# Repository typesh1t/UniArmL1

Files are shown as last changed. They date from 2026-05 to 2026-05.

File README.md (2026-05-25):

<div align="center">

# UniArmL1

  <a href="https://www.unitree.com/" target="_blank">
    Unitree LOGO
  </a>

**UniArmL1** 开源 6-DOF 机械臂及遥操作框架

<!-- [![English](https://img.shields.io/badge/English-README-blue)](./README.md) [![中文](https://img.shields.io/badge/中文-README-green)](./README_zh.md) -->

</div>

<div align="center">
<table>
  <tr>
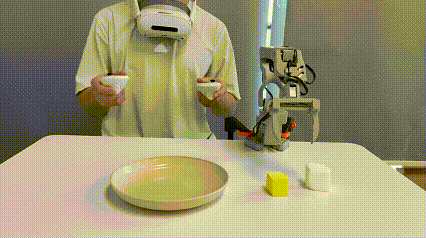
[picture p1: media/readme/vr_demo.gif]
VR demo
    <td></td>
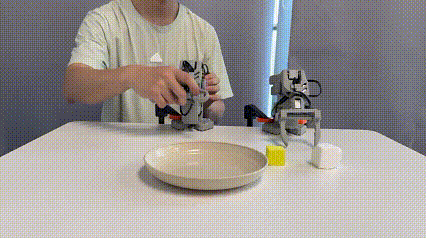
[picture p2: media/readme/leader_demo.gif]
Leader demo
    <td></td>
  </tr>
</table>
</div>

## ✳️ 概述

当前项目 UniArmL1 是一个轻量化的开源 6-DOF 机械臂及遥操作框架，支持三种控制模式与标准化数据采集，采集数据可无缝对接 [unitree_lerobot](https://github.com/unitreerobotics/unitree_lerobot) 进行模仿学习训练与部署。

**核心功能：**

- 🎮 **遥操作控制** — VR 手柄 / 键盘 / 主从臂三种模式实时控制 UniArmL1
- 📦 **数据采集** — 固定频率录制关节角度与相机图像，输出标准格式数据集
- 🔄 **训练对接** — 采集数据可直接用于 [unitree_lerobot](https://github.com/unitreerobotics/unitree_lerobot) 模仿学习训练

**完整流程：**

`硬件准备` → `校准` → `配置环境` → `遥操作 & 数据采集` → `训练` → `部署`

## 🔧 硬件准备

UniArmL1 机械臂的BOM 清单、组装指南与 3D 打印文件请参考：

👉 [unitree_UniArmL1_hardware](hardware/README_zh-CN.md)

<div align="center">
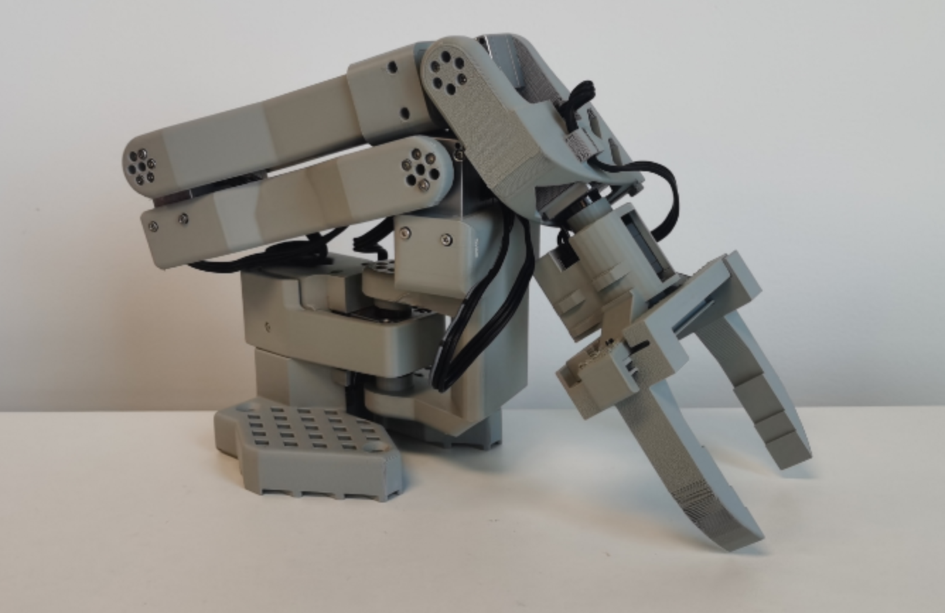
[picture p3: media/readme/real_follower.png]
Follower
   
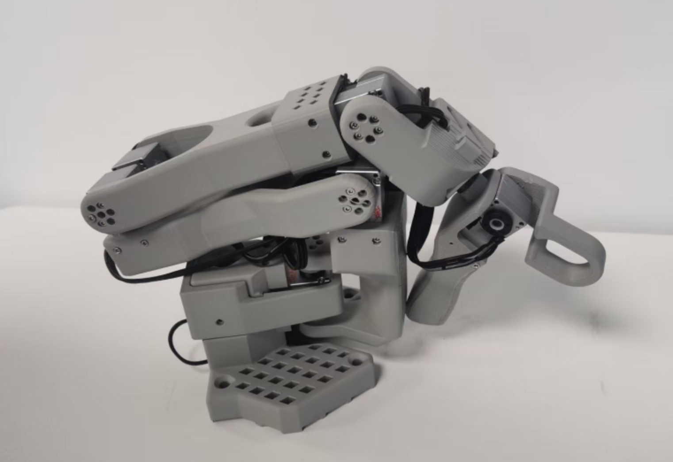
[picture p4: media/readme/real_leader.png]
Leader
    
</div>

## 📥 配置环境

### **1. 克隆仓库**

```bash
git clone https://github.com/unitreerobotics/UniArmL1
cd UniArmL1
```

### **2. 安装依赖**

该脚本会安装全部依赖（含VR模式）：
```bash
bash setup.sh
```

### **3. VR环境配置**

使用VR遥操需额外配置以下步骤。VR 手柄模式需要安装 xrobotoolkit SDK，请参考 [xrobotoolkit 文档](https://github.com/XR-Robotics) 进行配置。

#### 3.1 PC 上安装 XRoboToolkit-PC-Service
```bash
wget https://github.com/XR-Robotics/XRoboToolkit-PC-Service/releases/download/v1.0.0/XRoboToolkit_PC_Service_1.0.0_ubuntu_22.04_amd64.deb

sudo dpkg -i XRoboToolkit_PC_Service_1.0.0_ubuntu_22.04_amd64.deb
```

#### 3.2 Pico 上安装客户端
- 下载 APK: https://github.com/XR-Robotics/XRoboToolkit-Unity-Client/releases/download/v1.1.1/XRoboToolkit-PICO-1.1.1.apk
- 将 Pico 连接电脑，把 APK 拖入 Pico Download 文件夹
- 在 Pico 中安装 APK

可以在资源库中找到 XRoboToolkit app。

## 🛠️ 遥操作

### **1. 检查端口**

```bash
conda activate UniArmL1
# 查看串口设备
python teleop/scripts/check_port_all.py
```

如果串口权限不足：

```bash
sudo chmod 777 /dev/ttyACM*
```

### **2. 校准**

首次使用或更换电机后，需要先完成机械臂校准。校准前请先确认主臂和从臂对应的串口号，并根据实际情况修改 `--port` 参数。

完整校准指令、零位姿态和关节旋转步骤请参考：[[校准过程]](hardware/README_zh-CN.md#15-校准过程)

> ⚠️ **未校准将无法正常控制机械臂！** 校准前请确保机械臂已正确组装并通电。

### **3. 修改配置文件**

默认配置保存在 `teleop/teleop_config.yaml`，可直接修改，也可通过命令行参数覆盖，详见[参数说明](#parameters)。

### **4. 启动遥操作**
#### 4.1 VR 手柄模式

<div align="center">
   VR demo
</div>

```bash
python teleop/teleop.py -i vr
```
VR 头戴打开 XRoboToolkit app，输入 PC 端IP，点击连接，勾选控制面板中的 controller、send；电脑端打开 XRoboToolkit-PC-Service软件，按住手柄侧键即可开始遥操作。

#### 4.2 键盘模式
启动之后按住某个方向键机械臂会对应缓慢移动。
```bash
python teleop/teleop.py -i keyboard
```
具体操控机械臂的按键会在终端中说明，也可以在代码中查看。

#### 4.3 主从遥操模式
<div align="center">
   Leader demo
</div>
使用另一条 UniArmL1 作为主臂，直接映射关节角度：

```bash
python teleop/teleop.py -i leader --port /dev/ttyACM1 --leader-port /dev/ttyACM2
```

主臂处于零阻尼模式，从臂直接跟随主臂关节角度。

## 📦 数据采集

添加 `--record` 即可在遥操作过程中录制数据：

```bash
python teleop/teleop.py -i vr --record --task-dir ./data/pick_place --task-goal "pick up the cup"
```

## 🧑‍✈ 参数说明 

以下是 `teleop.py` 支持的命令行参数及其说明：

- `--input`, `-i`: 输入源模式，可选值：`vr` (VR 手柄)、`keyboard` (键盘)、`leader` (主从臂)。默认值：`vr`。
- `--port`, `-p`: 从臂串口端口。默认值：`/dev/ttyACM1`。
- `--leader-port`: 主臂串口端口，仅在主从模式下使用。默认值：`/dev/ttyACM2`。
- `--urdf`: URDF 文件路径。默认值：`assets/uniarml1/urdf/UniArmL1.urdf`。
- `--mesh-dir`: 网格目录路径。默认值：`assets/uniarml1/urdf/`。
- `--cameras`, `-c`: 相机配置，格式为 `name:id`，例如 `head:0 wrist:2`。可以指定多个。
- `--no-camera`: 禁用相机显示。默认不启用。
- `--record`, `-r`: 启用数据录制。默认不启用。
- `--task-dir`: 录制数据目录。默认值：`./data/teleop`。
- `--task-goal`: 任务目标描述。默认值：空字符串。
- `--record-hz`: 录制频率 (Hz)。默认值：50。
- `--meshcat`: 启用 Meshcat 可视化。默认不启用。
- `--vr-scale`: VR 增量缩放因子。默认值：1.2。

## 🕊 训练部署
采集的数据可直接用于 [unitree_lerobot](https://github.com/unitreerobotics/unitree_lerobot) 的模仿学习训练与部署，详见 [unitree_lerobot 文档](https://github.com/unitreerobotics/unitree_lerobot)。

<div align="center">
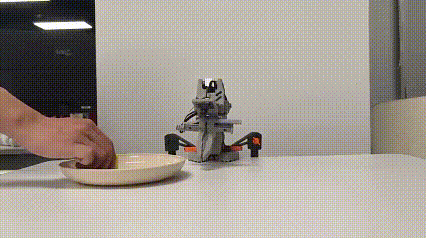
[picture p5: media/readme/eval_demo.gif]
UniArmL1 策略推理演示
   
</div>

## 🎉 致谢

- [lerobot](https://github.com/huggingface/lerobot) — 开源机器人模仿学习框架，提供数据采集、训练和部署的完整工具链
- [SO-ARM100](https://github.com/TheRobotStudio/SO-ARM100.git) — 开源机械臂硬件设计与组装指南
- [xr_teleoperate](https://github.com/unitreerobotics/xr_teleoperate.git) — Unitree XR 遥操作框架，提供了多种控制模式和数据采集功能
- [unitree_lerobot](https://github.com/unitreerobotics/unitree_lerobot.git) — Unitree 基于 LeRobot 的模仿学习实现，用于训练和部署机器人策略

## 许可证

本项目采用 Apache License 2.0 许可证 - 详见 [LICENSE](LICENSE) 文件。

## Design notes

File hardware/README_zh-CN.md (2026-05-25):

<div align="center">

   <h1 align="center"> Open UniArmL1 </h1>
  <a href="https://www.unitree.com/" target="_blank">
    Unitree LOGO
  </a>
  <!-- <p align="center">
    <a href="README.md"> English </a> | <a>中文</a>
  </p> -->
</div>

# 0. 📖 介绍
UniArmL1 是宇树科技设计与开发的 6-DOF 机械臂，现已开源，欢迎大家使用与进一步开发，一起帮助让面向机器人领域的端到端AI技术更加易于获取和使用！
<div align="center">
   UniArmL1 follower
   UniArmL1 leader
</div>

通过标准化软硬件接口，UniArmL1 能快速接入现有宇树平台，降低集成与二次开发门槛，缩短从原型到应用的周期。

# 1. 构建你的UniArmL1
我们目前仅支持自行构建的方式，步骤如下：

1. 首先需要购买非打印零部件，购买清单见[1.1 采购零件](#11-采购零件)
2. 3D打印机械臂主体零件，具体说明见[1.2 打印零件](#12-打印零件)
3. 请参照我们的电机配置方法配置电机[1.3 电机配置](#13-电机配置)
4. 请跟随我们的[1.4 装配指导](#14-装配指导)

## 1.1 采购零件

如需搭建遥操作系统，请购买以下两套机械臂所需的全部部件。

### 主从机械臂零件清单：

| 部件 | 数量 | 单价 (RMB) | 购买链接 |
| ---- | ---- |---| --- |
| J288舵机| 16 | 599 | [Alibaba](https://detail.tmall.com/item.htm?id=1013064765085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) |
| 电机控制板 | 2 | 99 | [Alibaba](https://detail.tmall.com/item.htm?id=1013064765085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)| 
| 腕部相机 | 1 | 190 | [Alibaba](https://item.taobao.com/item.htm?id=739033087984&skuId=5267839634724)|
| 全局相机 | 1 | 183 | [Alibaba](https://detail.tmall.com/item.htm?id=631167230453&skuId=6105245094571)| 
| USB-C 数据线 | 2 | 23.5 | [Alibaba](https://e.tb.cn/h.itebBTDTzUCVMnm?tk=Ia1Z5jXFDnAMF278)| 
| 24V-5A电源适配器 | 2 | 30 | [Alibaba](https://item.taobao.com/item.htm?id=769661452640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)|
| 电源转换线 | 2 | 9.9 | [Alibaba](https://item.taobao.com/item.htm?id=944933463975&skuId=5850600264594)|
| 固定器 | 4 | 7.8 | [Alibaba](https://detail.tmall.com/item.htm?id=801399113134&skuId=5817329226938) |

请额外准备紧固件若干：72× M2×10 螺栓，92× M2×8 螺栓，14× M2×5 螺栓，4× M3×6 螺栓，4× M3 螺母

## 1.2 打印零件
### 步骤1：选择打印机
我们提供的 STL 文件已可直接用于多种 FDM 3D 打印机进行打印。下面列出了经过测试和建议的打印设置，不过其他设置也可能同样适用。
1. 材料：PLA+
2. 喷嘴直径与打印精度：使用 0.4 mm 喷嘴时，层高为 0.2 mm
3. 填充密度：30%
4. 示例打印机：[Bambu Lab A/P/X-series](https://bambulab.com)，[Prusa MINI+](https://www.prusa3d.com/product/original-prusa-mini-semi-assembled-3d-printer-4/), [UP Plus 2](https://shop.tiertime.com/product/tiertime-up-plus-2-3d-printer/) 等

### 步骤 2：设置打印机
1. 按照打印机对应的说明，确保打印机已完成校准，并且打印床已正确调平 
2. 清洁打印床，确保表面没有灰尘或油污。如果用水或其他液体清洁了打印床，请先将其彻底擦干
3. 如果你的打印机有此建议，可使用普通固体胶，在打印床的打印区域均匀涂上一层薄薄的胶水，避免局部堆积或涂抹不均
4. 按照打印机对应的说明装入打印耗材
5. 确保打印机设置与上文建议的参数一致；大多数打印机会提供多个选项，选择最接近建议值的设置即可
6. 将支撑设置为“开启支撑”，阈值角度为30°
7. 水平轴向的螺丝孔内部不应生成支撑

### 步骤3：打印部件
用于 leader 和 follower 的所有零件都已经整合在单个文件中，并且已为 3D 打印做好优化处理；零件朝向也已正确设置，以尽量减少支撑结构并确保打印精度。
对于 220 mm × 220 mm 打印床尺寸的打印机，请打印以下文件：
- [打印文件](STL/UniArmL1.3mf)

>注意！末端由于Follower需要加装相机，Leader需要加装把手，模型并不相同，但是都在一个打印文件中，可以参考部件朝向。

如果有不同的打印或替换需求，下面的表格包含了所有单独的文件：
1. 通用部分：

| Part | Link  |
|---|---|
| Base.stl | [Base.stl](STL/common/Base.stl) |
| Base_motor_holder.stl | [Base_motor_holder.stl](STL/common/Base_motor_holder.stl) |
| Rotation_Pitch.stl | [Rotation_Pitch.stl](STL/common/Rotation_Pitch.stl) |
| Under_arm.stl  | [Under_arm.stl](STL/common/Under_arm.stl) |
| Upper_arm.stl  | [Upper_arm.stl](STL/common/Upper_arm.stl) |
| Under_motor_holder.stl | [Under_motor_holder.stl](STL/common/Under_motor_holder.stl) |
| Wrist_roll_pitch.stl | [Wrist_roll_pitch.stl](STL/common/Wrist_roll_pitch.stl) |

2. Leader-专有部分

| Part | Link  |
|---|---|
| Handle.stl | [Handle.stl](STL/leader/handle/handel.stl) |
| Trigger.stl | [Trigger.stl](STL/leader/handle/Trigger.stl) |

3. Follower-专有部分

| Part | Link  |
|---|---|
| Finger.stl | [Finger.stl](STL/follower/eef/Finger.stl) |
| Gripper_gear.stl | [Gripper_gear.stl](STL/follower/eef/Gripper_gear.stl) |
| Gripper_shell.stl | [Gripper_shell.stl](STL/follower/eef/Gripper_shell.stl) |
| Guide_rail.stl | [Guide_rail.stl](STL/follower/eef/Guide_rail.stl) |

4. 相机支架

| Part | Link  |
|---|---|
| Camera_mount_up.stl | [Camera_mount_up.stl](STL/follower/camera/Camera_mount_up.stl) |
| Camera_mount_down.stl | [Camera_mount_down.stl](STL/follower/camera/Camera_mount_down.stl) |

### 步骤4：移除支撑
1. 打印完成后，用小铲将零件从打印床上铲下来。
2. 然后去除零件上的所有支撑材料。

## 1.3 电机配置
各个关节分别需要使用哪些电机，如下表所示：
| 关节名称 | 数量  | 下标 |
|---|---|---|
|Shoulder Pan(base)| 1 | 0 |
|Shoulder Lift| 2 | 1&6 |
|Elbow Flex| 2 | 2&7 |
|Wrist Flex| 1 | 3 |
|Wrist Roll| 1 | 4 |
|Gripper| 1 | 5 |

首先下载上位机软件 [电机调试助手](doc/Motor_Assistant_V1.1.0.zip)，目前只支持win10和win11系统。

控制板一端连接PC，一端连接电机，在功能区可以选择电机型号、选择通信串口、控制的电机 ID 号。

修改 ID：将当前电机 ID 更改为指定的目标 ID。操作成功后，电机 ID 将更新为目标值，同时上位机软件中控制的电机 ID 也将同步切换至新 ID。

按照上表所示依次修改电机ID，主从臂同理。
## 1.4 装配指导
此为 Follower 在 solidworks 中的总装图，仅供参考：
<div align="center">
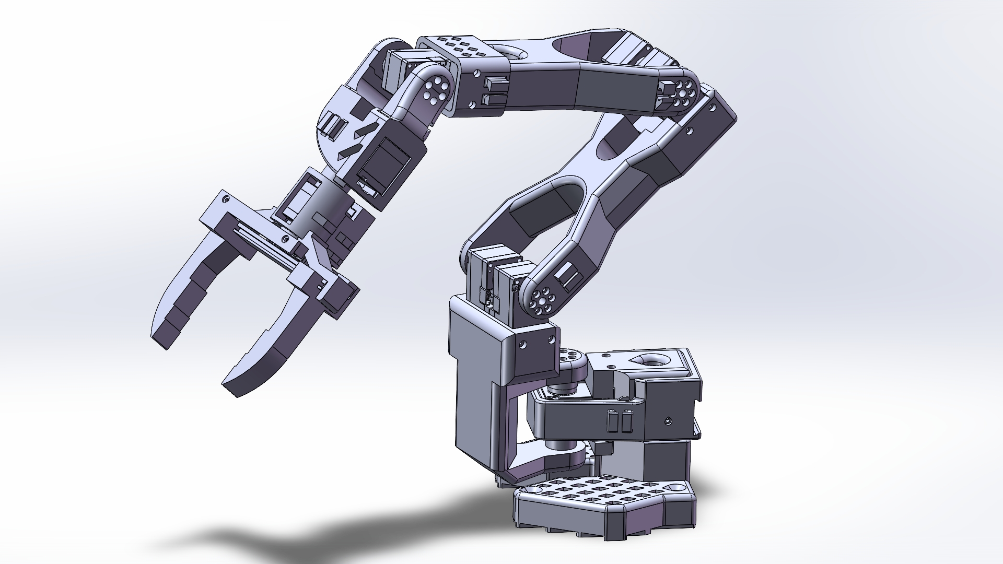
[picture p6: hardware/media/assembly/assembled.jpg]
follower
   
</div>

以下为分步装配过程：

1. 基座与0号电机：
<div align="center">
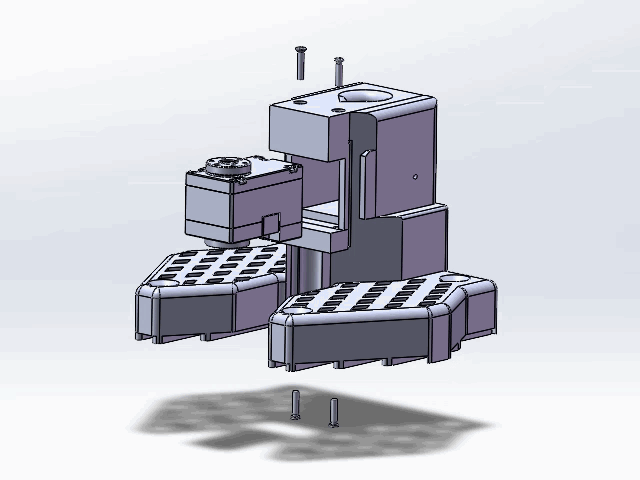
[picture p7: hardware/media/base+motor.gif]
base and motor
   
</div>

2. 基座上套上电机套，电机转轴处固定 Rotation_Pitch:
<div align="center">
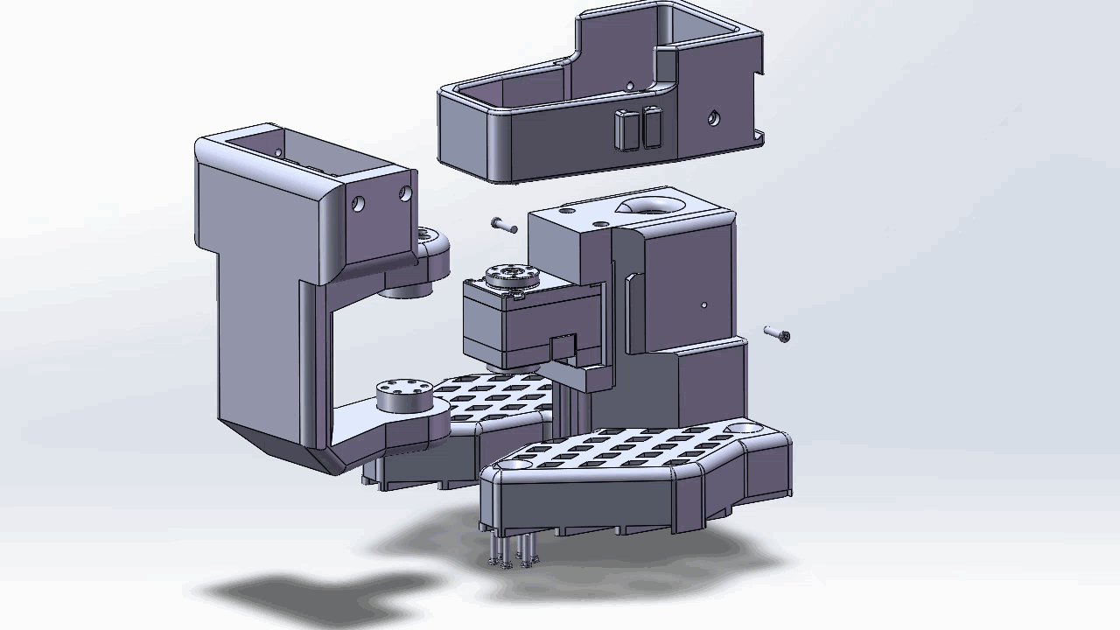
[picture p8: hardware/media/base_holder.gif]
base holder
   
</div>

3. 注意，**ID为1和2的电机输出轴是朝向机械臂右侧，将排线插入电机后**，再在 Rotation_Pitch 上固定双电机，arm上的同理。
<div align="center">
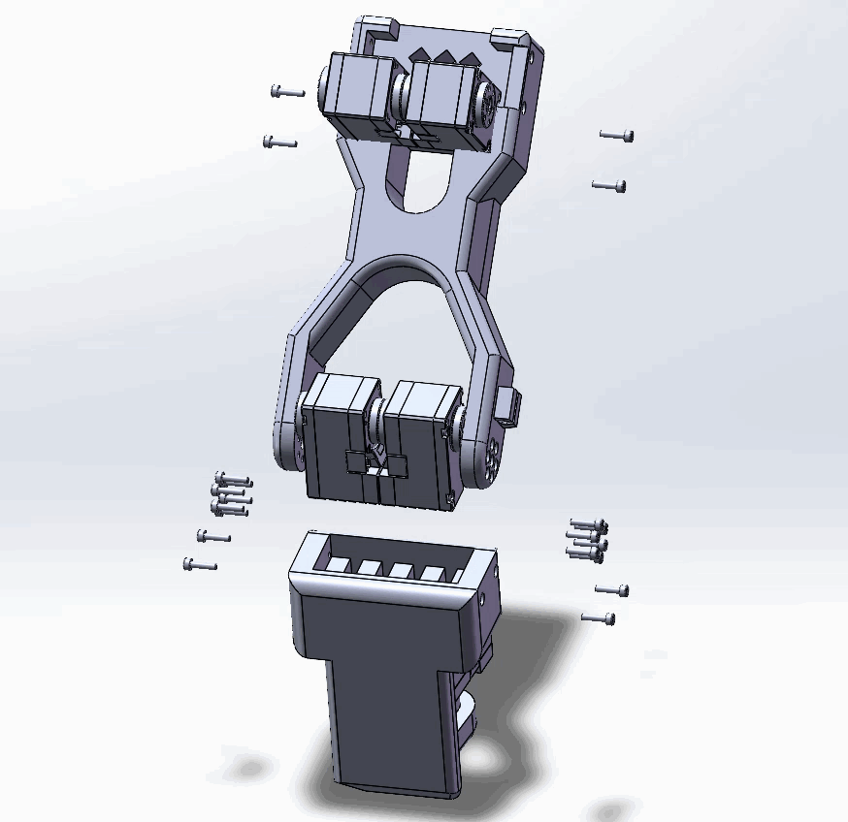
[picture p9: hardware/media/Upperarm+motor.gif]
upperarm and motor
   
</div>

4. arm上塞入电机后加装固定保护套，再固定 Wrist_roll_pitch.
<div align="center">
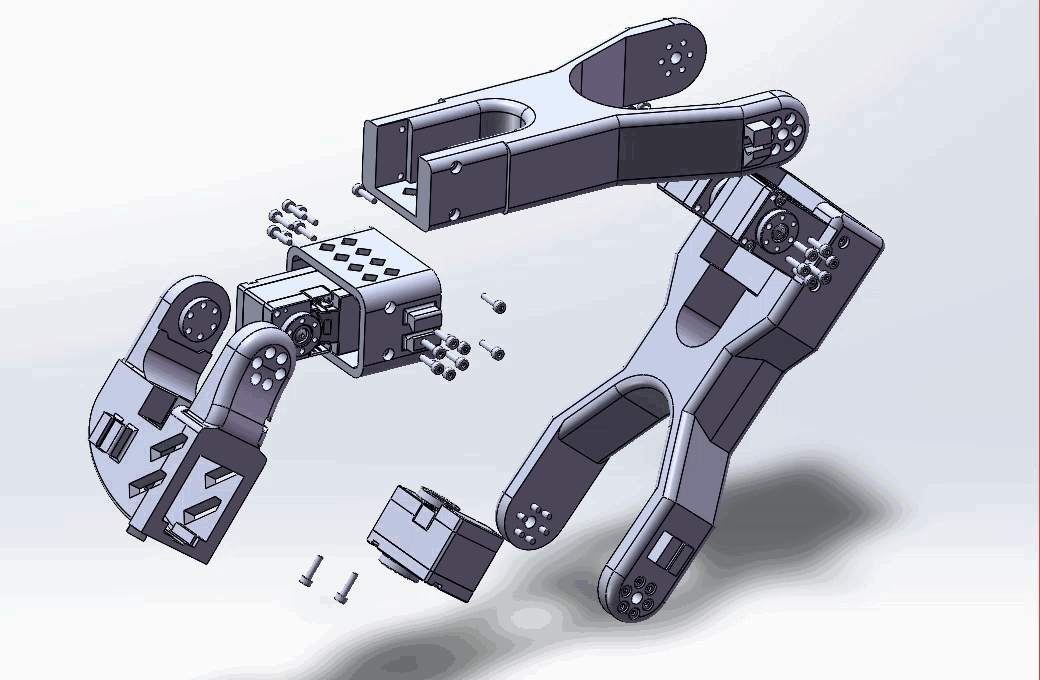
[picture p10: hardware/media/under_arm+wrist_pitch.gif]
under arm and wrist pitch
   
</div>

5. 最后末端夹爪的装配，有两个注意点
    - **先固定外壳和motor4**，再将motor5塞入外壳固定，其上固定齿轮连接件。
    - **先将平行夹爪手指与导轨配合后**，再放到外壳上固定
<div align="center">
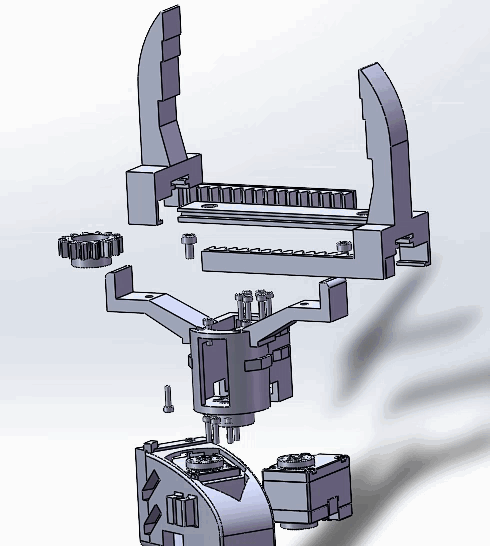
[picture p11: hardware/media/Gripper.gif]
gripper assembly
   
</div>

## 1.5 校准过程
请根据自己查找到的端口修改 --port 参数。

### 从臂（Follower）
1. 校准指令：
```bash
python teleop/scripts/calibrate_uniarml1.py --port /dev/ttyACM1 --id follower
```
2. 将从臂放置在零位，确认姿态后回车。
<div align="center">
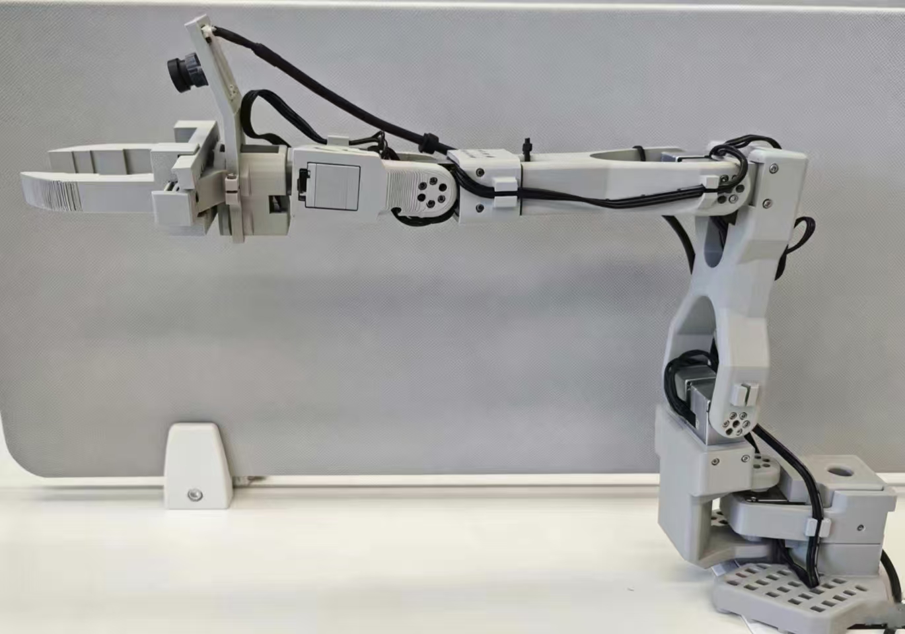
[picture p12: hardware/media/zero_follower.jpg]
follower zero pose
   
</div>
3. 依次旋转每个关节到左右最大的可移动范围，完成后回车。
<div align="center">
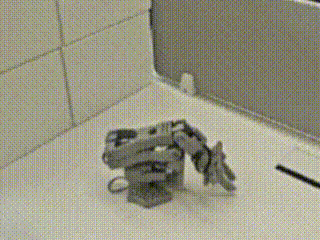
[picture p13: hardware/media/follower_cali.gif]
   
</div>

### 主臂（Leader）
1. 校准指令：
```bash
python teleop/scripts/calibrate_uniarml1.py --port /dev/ttyACM3 --id leader
```
2. 将主臂放置在零位，确认姿态后回车（两种姿态，按使用习惯选择其一）。
<div align="center">
<table>
  <tr>
    <td>
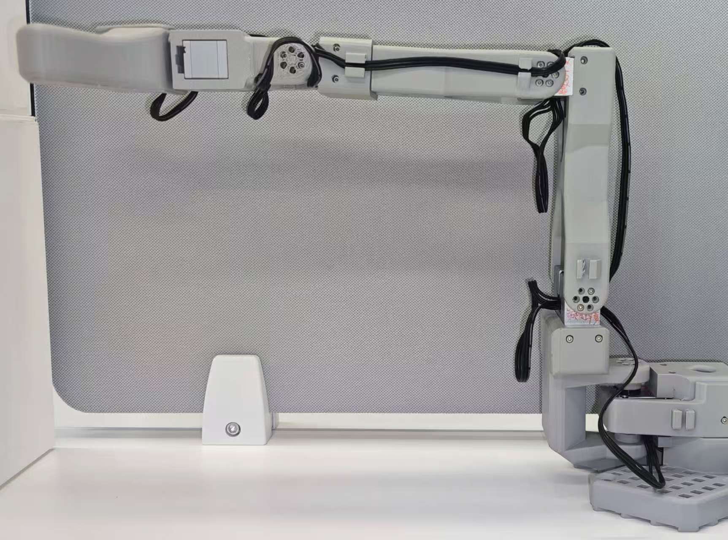
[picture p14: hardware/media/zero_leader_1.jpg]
leader zero pose 1
      
    </td>
    <td>
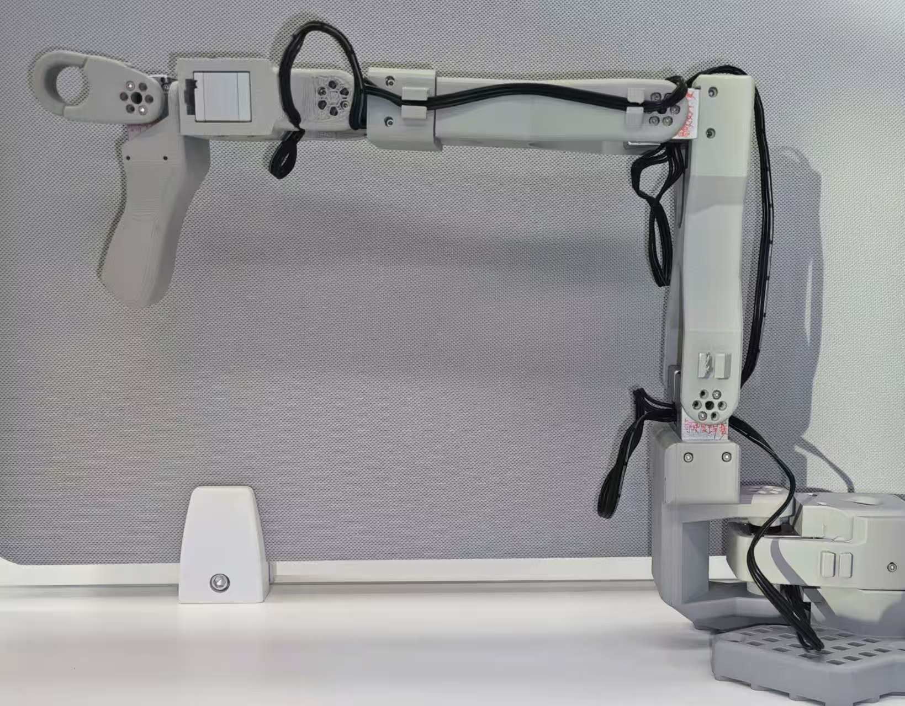
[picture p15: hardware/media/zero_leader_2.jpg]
leader zero pose 2
      
    </td>
  </tr>
</table>
</div>
3. 按提示依次旋转每个关节到左右最大的可移动范围，腕部关节主臂与从臂应左右旋转相同范围，完成后回车。
<div align="center">
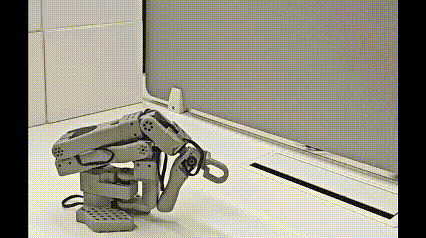
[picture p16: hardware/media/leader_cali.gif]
   
</div>

校准数据保存在 `~/.cache/unitree/calibration/` 目录下。

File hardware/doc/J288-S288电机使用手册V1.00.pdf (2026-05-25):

1、电机概述

永磁同步电机主要由定子和转子两个部分组成，定子与电机壳体刚性连接，转子可以转动并粘贴有 永磁体。
我们知道，在永磁铁外部某个方向施加一个恒定方向的磁场，永磁体受到外部磁场会产生引力和斥 力，产生旋转的力矩，最终永磁铁会被吸引、旋转、并静止在与外部施加磁场平行的方向。一个典型的 例子就是在地球磁场下的指南针，指南针会转动到指向地球南北极的方向（磁针与地磁方向平行）。同 样的，如果这个固定的磁场开始转动，那么永磁体也会跟着转动，永磁体会尽量跟随外部磁场与自身磁 场平行夹角最小的方向转动。
这样我们就可以通过旋转磁场来令永磁体旋转到指定角度。同时，永磁体在外部施加的磁场中，所 产生的力矩大小和永磁体与磁场方向的夹角有关，所以我们也可以通过控制外部磁场方向和永磁体磁场 方向的夹角来控制永磁体产生的力矩。
回到电机的角度来说，就是我们可以通过控制定子上三个绕组电流的大小与电流方向，来控制定子 的磁场方向与磁场大小，从而达到了控制转子的输出扭矩。而这种控制方法就是永磁同步电机的矢量控 制（Field-Oriented Control，以下简称 FOC）。
2、FOC 控制简介

FOC 控制有许多独特的优势，它可以让我们对永磁同步电机进行“像素级”的控制，实现很多传统 电机控制方法所无法达到的效果：
1.可以在低转速下保持精确控制；
2.可以很好地实现电机换向旋转；
3.能够对电机进行力矩、速度、位置三个闭环控制；
4.FOC 控制的永磁同步电机噪音较小。
正如永磁同步电机概述节所述，FOC 控制的基础就是旋转磁场。在下图的磁场矢量中，我们看到电 机定子的三个线圈 a、b、c 可以产生三个方向的磁场 Ba、Bb、Bc 它们能合成电机中的磁场 B。FOC 控 制器根据当前永磁体转子的角度、角速度、期望的输出力矩以及采样测量得到的 a、b、c 三个线圈的电 流，计算得到三个线圈的电压通断状态与通断时间，进而通过 MOS 管来控制三个线圈的电压通断。这样 就可以合成我们期望的磁场 B，进而拖动电机转子按照我们期望的方式运动。

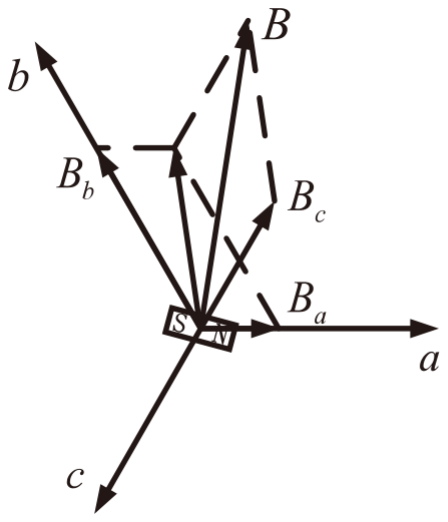
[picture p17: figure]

图 1 FOC 的磁场矢量
3、电机硬件与编码器概述

机器人关节电机的核心构件是电机驱动板、定子、转子和行星减速器。因为电机适合在高转速低力 矩的工况下工作，而我们的机器人需要的是低转速高力矩，因此电机转子需要通过一个减速器减速之后， 再输出力矩。
编码器（encoder）是用来测量旋转角度的传感器。编码器分为增量编码器、多圈绝对位置编码器 与单圈绝对位置编码器等多种。我们在此只详细讨论关节电机实际应用的单圈绝对位置编码器。 关节电机的单圈绝对位置编码器安装在电机转子上。对于单圈绝对位置编码器（以下简称编码器）， 可以将它当做一个“时钟表盘”。我们每次看表的时候，都可以读到当前的日期和时间，例如 4 月 1 日 23 点。如果时间经过了 2 个小时，那么时钟转过了 4 月 1 日 24 点，日期会增加 1 天变成 4 月 2 日， 时间重新从 0 点开始计时，变成了 4 月 2 日 1 点。 为了方便计算经过的时间，我们也可以说现在是 4 月 1 日 25 点。看上去 25 点超过了一天 24 个小时的范围，实际上是因为日期增加了 1 天。 单圈绝对位置编码器也是同样的道理。每次开机上电后，我们的转子可能处于任意位置，编码器会
告诉我们转子所处的角度位置（0 至 | 2π | 之间的某个值）。如果转子旋转转过了2π | 这个角度位置，编
码器也能够记录转过的圈数增加了 1 ，从而输出一个超出 0 至 | 2π | 范围的角度位置。看上去编码器也
能够输出超过一圈的角度位置，那么为什么叫它“单圈”绝对位置编码器呢？原因在于这种编码器在断 电之后不能够储存之前旋转的圈数，我们以下面这个例子来说明。
假设当前编码器输出的角度值为2.3π ,这意味着编码器在开机之后经过了 | 2π | ,旋转圈数从 0 变
为 1，同时编码器当前位于0.3π 这个位置。此刻我们将编码器关机，不做任何旋转，再将编码器开机，
那么此时编码器输出的角度值就会变为 | 0.3π | 。因为关机之后旋转圈数重置为 0，所以编码器只会输出
当前位置 | 0.3π | 。

4、电机的混合控制

关节电机作为一个高度集成的动力单元，其内部已经封装了电机底层的控制算法。作为用户，只需 要给关节电机发送相关的命令，电机就能完成从接收命令到关节力矩输出的全部工作。 对于电机的底层控制算法，唯一需要的控制目标就是输出力矩。可是对于机器人，我们通常需要给 关节设定位置、速度和力矩。这时就需要对关节电机进行混合控制。
宇树科技的关节电机包含如下 5 个控制指令：
1. 前馈力矩：τff ;
2. 期望角度位置：pdes ;
3. 期望角速度：ωdes ;
4. 位置刚度：kp;
5. 阻尼系数：kd;
在关节电机的混合控制中，使用 PD 控制器将电机在输出位置的偏差反馈到力矩输出上：
τ = τff + kp × (pdes − p) + kd × (ωdes − ω)
式中，τ | 为关节电机的电机转子输出力矩，p | 为电机转子的当前角度位置，为 | ω | 电机转子的角速
度。在实际使用关节电机时，需要注意将电机输出端的控制目标量与发送的电机转子的指令进行换算。

5、电机的线路连接

我们使用单总线（1-Wire）作为物理层。物理层是指使用何种物理现象来表达和传输信息。实际上， 可以将单总线视为一种基于单线通信的串行接口。
单总线仅利用一根数据线（以及公共地线）进行双向数据传输。该总线采用特殊的通信时序，在同 一根线上实现设备数据传输。其单线连接方式极大简化了线缆连接，提高了硬件连接的可靠性，并降低 了布线成本。
单总线信号采用和 TTL 相同的串口时序表示逻辑电平，由于单总线仅使用一根数据线进行双向通信， 因此同一时刻总线上只能进行一个方向的通信，即半双工通信。总线通常由一个主机（上位机）控制通

信时序。主机发送的指令中包含目标设备地址信息，总线上所有设备均会接收该指令，但只有地址匹配 的设备会响应并回复数据，从而完成一轮通信。
J288/S288 电机在单条总线上最多可支持 15 个电机（ID 范围为 0~14）。需特别注意，总线上严禁 出现 ID 相同的电机，否则会导致整条总线通讯异常；此外，波特率不同的电机也不得连接在同一总线上。 为了将运动控制指令发送给电机，我们需要通过串口将指令下发。电机通过单总线接口与上位机通 信，通信速率（波特率）固定为：6Mbps（8N1）。

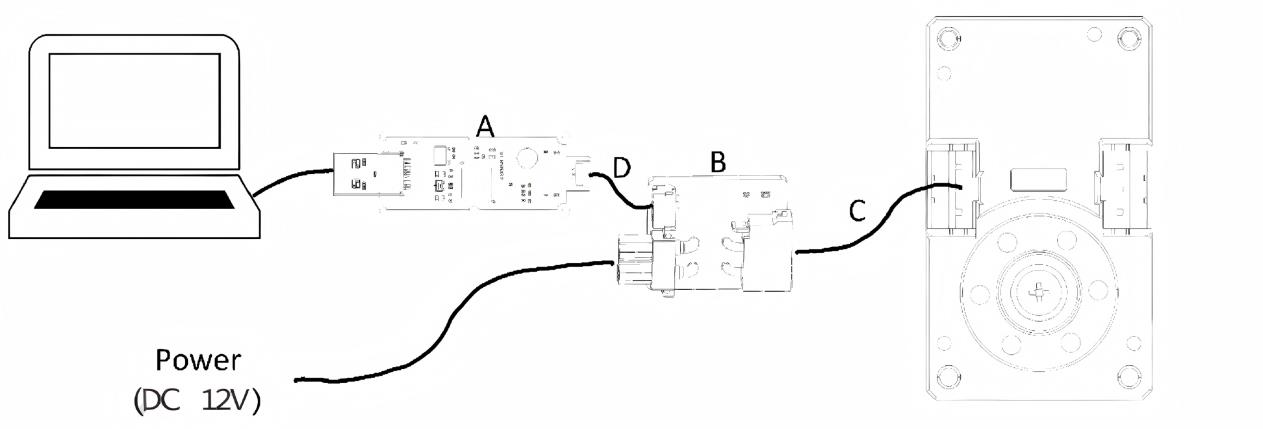
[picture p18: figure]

图 2 电机线路连接
如图 2 所示，接口采用 C 线缆连接至 B（XT30(2+2) 转接板），再通过 D（GH1.25-3 线缆）连 接到 A（单总线转 USB 模块），最终连接到电脑。
在使用个人电脑控制电机时，需将单总线接口通过 USB 转单总线适配器连接至上位机。接通 12 V 直流电源后，电机绿色指示灯开始闪烁，表示电机已正常开机。

6、电机配置及快速使用

通过电机调试助手，您可以对电机执行以下配置操作：
- 查询及修改 ID
- 修改电机波特率
- 查询版本号
- 恢复电机模式
- 临时关闭引导
- 清除故障
- 电机复位
- 固件更新

通过电机调试助手，您可以快速使用电机，实现以下功能
- 电机运动控制
- 数据曲线绘制

具体操作方法详见《电机调试助手使用指南》。

7、电机协议

考虑到部分用户可能会使用特殊平台来控制电机，在此我们将讲解如何编写自定义的电机控制程序。 根据本节介绍的方法，读者可以在任何满足硬件要求的平台上向电机发送控制命令并接收电机状态反馈。 协议中的所有参数均为转子端数据，减速比为 288.35，若需将转子数据换算为输出端数据，则需乘以或

除以该减速比。
N215-288 电机采用串口通信，通信标准为单总线（1-Wire），波特率为 6.0 Mbps。串口的数据位 为 8 bit，无奇偶校验位，停止位为 1 bit 。需要注意的是为了提高电机的通信频率，我们使用了 6.0 Mbps 这一很高的波特率，用户需要检查自己的硬件是否支持这么高的波特率。如果您的硬件无法支持该 波特率，可以使用 Unitree 的 USB 转单总线（1-Wire）模块。 在控制电机时，我们会通过串口给电机发送一个长度为 20 字节的命令，之后电机会返回一个长度 为 26 字节的信息 。如果不给电机发送命令，那么电机也不会返回状态。电机发送命令格式与返回格式 见下面结构体，结构体详细说明了各个字节的含义，下面我们解释其中部分细节。 首先，在发送给电机的命令中，第 5 和第 6 字节表示电机前馈力矩τff ，其中 256000 对应 1 牛·米

(NM)。这相当于我们对前馈力矩值乘以了 256000，然后将其赋值给一个 2 字节的带符号短整型(signed
short int)变量。在此赋值过程中会进行强制取整，从而使我们能够仅用两个字节来传输前馈力矩τff | 数
据。当电机接收到此数据后，只需将其除以 256000，即可还原前馈力矩τff | 的实际数值。这种方法虽然

会损失一定精度，但对于实际应用场景而言完全满足需求。
此外，需要注意的是，对于一个 2 字节(16 位)的变量，其中 1 位用作符号位表示正负，因此只有 15 位可用于表示数值大小。这意味着命令中τff 的数值不能2

15超过特定上限。考虑到我们曾对原始数据

τff 乘以了 256000，因此其绝对值存在相应的上限值：

|τff| <

2

15
256000 = 0.128

同时需要注意的是，由于赋值过程中存在强制取整操作，τff 因此数值越大，保存的小数精度就越

低。结构体变量注释中提到的"256000 表示 1"实际上是指上文所述的乘以 256000 的操作，其他变量中类 似的"xx 表示 1"描述也遵循相同的原理。
并且，对于 2 个字节的 | τ | 变量来说，它的低位在前，即第 5 字节，高位在后，即第 6 字节。在发
送命令和接收状态的末尾，我们可以看到一个 4 字节的 CRC32 校验。在命令发送之前，我们会计算这些 命令字节的发送前 CRC 校验值，并且和命令一起发送给电机。当电机收到命令之后，还会根据收到的命 令计算发送后 CRC 校验值。
如果数据传输过程中没有发生任何错误，那么发送前 CRC 校验值等于发送后 CRC 校验值。如果在数 据传输过程中出现了数据错误，那么发送后 CRC 校验值的计算结果就与发送前 CRC 校验值不相等， 电机 就能够知道数据发生了损坏，从而帮助我们避免错误数据。

// 电机控制命令数据包 20 字节
typedef struct
{
uint8_t head[2]; // 帧头 0xFE 0xEE 参与 CRC
uint8_t id : 4; // 电机 ID: 0-14, 15 表示向所有电机广播数据(此时无返回) uint8_t status : 3; // 工作模式: 0.锁定 1.FOC 闭环
uint8_t timeout : 1; // Master->Motor: 0.禁用超时保护 1.开启 （默认 1s 超时） uint8_t res; // 保留位
int16_t tor_des; // 期望转子输出扭矩 unit: N.m 256000 表示 1NM
int16_t spd_des; // 期望转子输出速度 unit: rad/s 2.56/2π 表示 1rad/s int32_t pos_des; // 期望转子输出位置 unit: rad 32768/2π 表示 1rad int16_t k_pos; // 期望转子刚度系数 unit: N.m/rad 1280000 表示 1 int16_t k_spd; // 期望转子阻尼系数 unit: N.m/(rad/s) 128000000 表示 1 uint32_t CRC32; // CRC32
} ControlData_t;

// 电机控制模式
typedef struct
{
uint8_t id : 4; // 电机 ID: 0-14, 15 表示向所有电机广播数据(此时无返回) uint8_t status : 3; // 工作模式: 0.锁定 1.FOC 闭环
uint8_t timeout : 1; // Master->Motor: 0.禁用超时保护 1.开启 （默认 1s 超时） // Motor->Master: 0.没有超时 1.触发超时保护(需要控制位发 0 清除)
} RIS_Mode_t;

// 2-电机返回数据 26 字节
typedef struct
{
uint8_t NoUse[2]; // 通信中不存在（结构体 4 字节对齐），在发送通信数据时必须去除该数据 位
uint8_t head[2]; // 帧头 0xFC 0xEE 不参与 CRC
RIS_Mode_t mode; // 电机控制模式
int8_t temp; // 壳体温度: -128~127°C
uint8_t sensor; // 绕组温度: 0-255°C
uint8_t vol; // 电机端电压 0-127.5V 255 表示 127.5V int16_t torque; // 当前转子扭矩 256000 表示 1NM int16_t speed; // 当前转子速度 2.56/2π 表示 1rad/s int32_t pos; // 当前转子位置 32768/2π 表示 1rad uint32_t MError; // 电机错误码: 0x0.正常 bit0 过流,... uint16_t OutPos : 13; // 输出端传感器 2^13 表示 1 圈 uint16_t ExFlag : 3; // 警告码
uint16_t res; // 保留位
uint32_t CRC32; // CRC32
} MotorData_t;

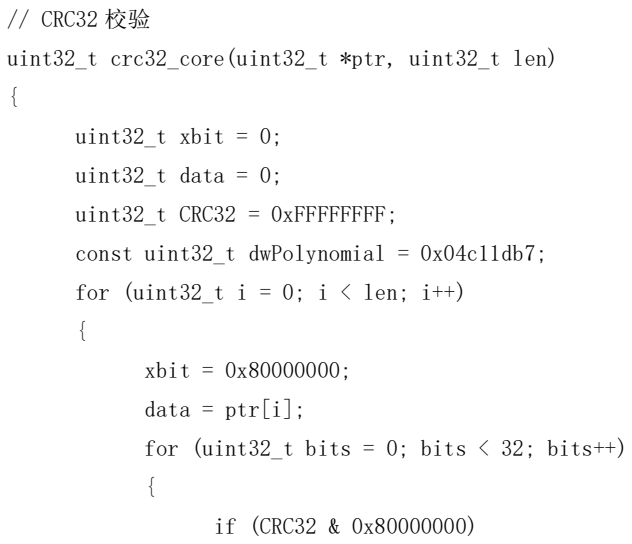
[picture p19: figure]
// CRC32 校验; uint32_t xbit = 0;; uint32_t data = 0;; uint32_t CRC32 = 0xFFFFFFFF;; for (uint32_t i = 0; i < len; i++); xbit = 0x80000000;; data = ptr[i];; if (CRC32 & 0x80000000)

uint32_t crc32_core(uint32_t *ptr, uint32_t len)

const uint32_t dwPolynomial = 0x04c11db7;

for (uint32_t bits = 0; bits < 32; bits++)

{
CRC32 <<= 1;
CRC32 ^= dwPolynomial;
}
else
CRC32 <<= 1;
if (data & xbit)
CRC32 ^= dwPolynomial;

xbit >>= 1;
}
}
return CRC32;
}

8、电机故障码表

当电机发生故障时，会触发对应的错误状态标识，且多个错误状态可同时存在。故障排除后，错误 状态将持续保留，直至接收到清除错误/复位指令或设备重新上电。 清除指令协议：电机控制协议中 status=6，tor_des=-256，spd_des=0，pos_des=0，k_pos=0，k_spd=0 复位指令协议：电机控制协议中 status=7
清除指令可在任意控制阶段插入，但当有错误正在发生或存在不支持该指令的错误时，该指令不会 执行；执行后电机会保持在 Mode0（停机）状态，等待新指令。 复位指令需在电机停止时使用，用于控制电机重启并重新执行上电后的各项检测；收到该指令后执 行时间约为 0.3 秒，在此期间电机不响应其他控制指令。 重新上电需在电机停止时操作，用于控制电机重启并重新执行上电后的各项检测；上电过程用时约 为 1.3 秒，在此期间电机不响应其他控制指令。
故障码 | 位(bit) | 说明 | 清除指令 | 复位指令/ 重新上电
0x01 | 0 | 过流 | | √
0x02 | 1 | 瞬态过压 | √ | √
0x04 | 2 | 持续过压 | √ | √
0x08 | 3 | 瞬态欠压 | √ | √
0x10 | 4 | 芯片过热 | √ | √
0x20 | 5 | MOS 过热/冷 | √ | √
0x40 | 6 | MOS 温度异常 | √ | √
0x100 | 8 | 壳体温度异常 | √ | √
0x200 | 9 | 绕组过热 | √ | √
0x400 | 10 | 转子编码器 1 错误 | | √
0x1000 | 12 | 输出编码器错误 | √ | √
0x2000 | 13 | 储存数据错误 | | √
0x4000 | 14 | 异常复位 | √ | √
0x10000 | 16 | 芯片验证错误 | | √

0x20000 | 17 | 标定模式 | √
0x80000 | 19 | 驱动版本过低 | √
0x100000 | 20 | 固件型号错误 | √
0x400000 | 22 | 硬件过流 | √
表 1.电机故障码表

9、警告码表

警告码 | 位(bit) | 说明 | 清除指令 | 复位指令/ 重新上电
0x01 | 0 | 低压电源异常 | √ | √
表 2.电机警告码表

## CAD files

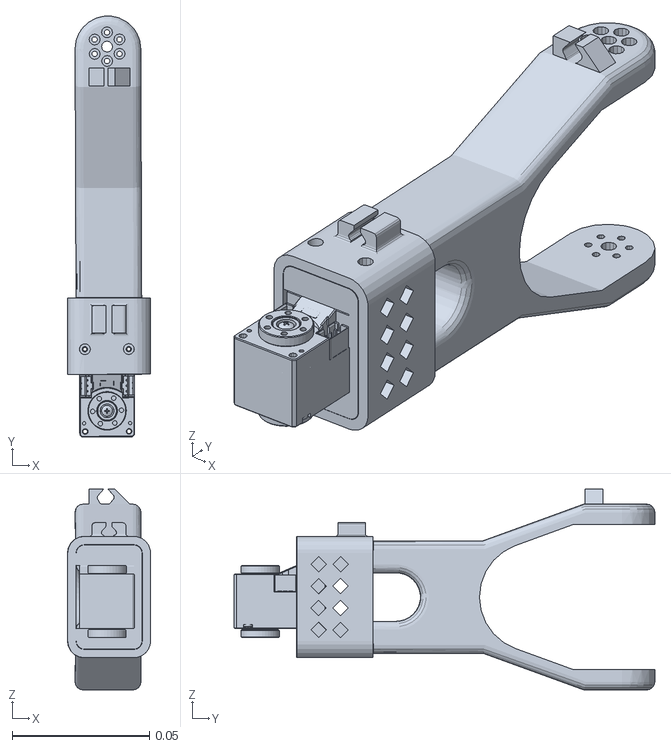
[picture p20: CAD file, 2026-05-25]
assets/uniarml1/meshes/Link_3.STL
0.0303 x 0.154 x 0.0733

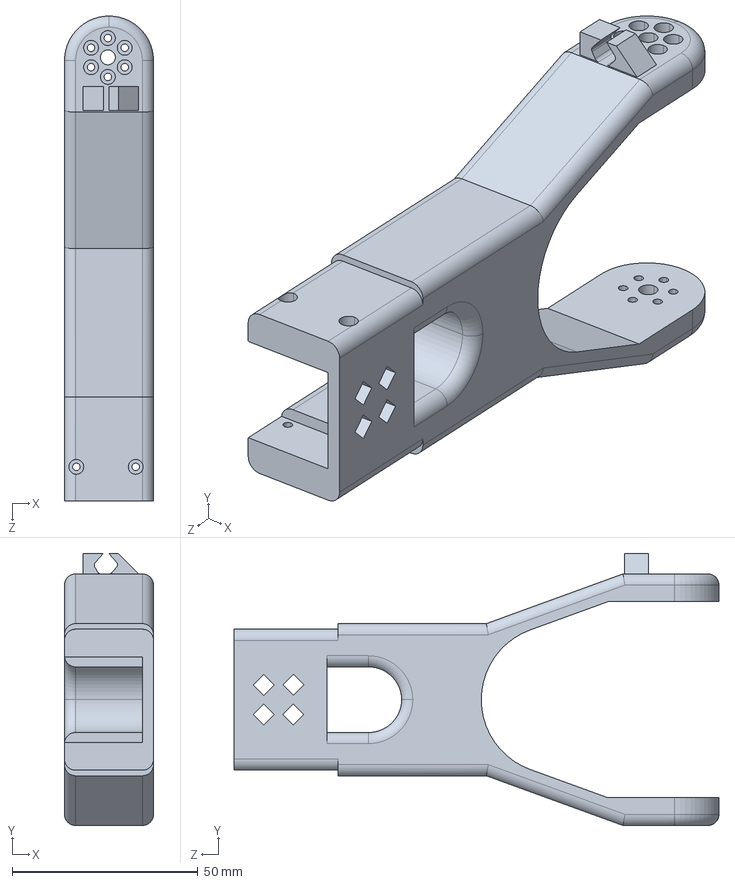
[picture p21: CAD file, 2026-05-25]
hardware/STEP/common/Under_arm.stp
24.0 x 73.3 x 130.7 mm

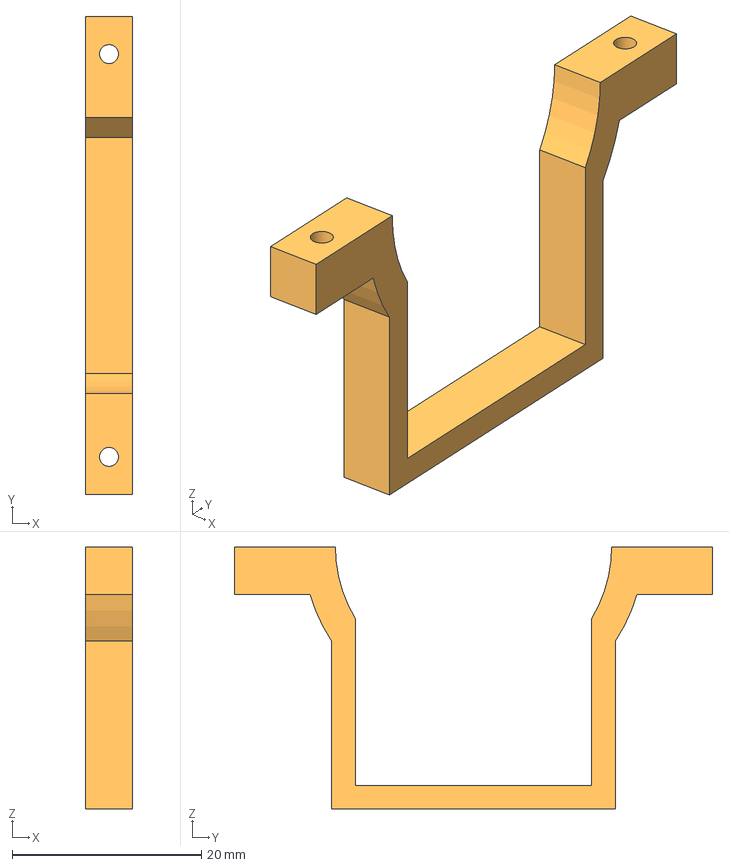
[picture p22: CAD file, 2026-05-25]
hardware/STEP/follower/camera/Camera_mount_down.stp
5.00 x 50.6 x 27.7 mm

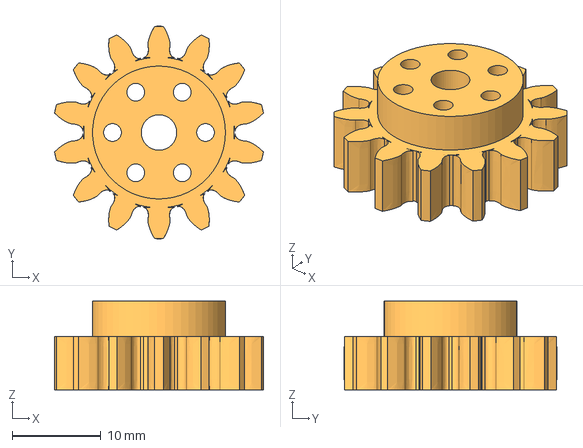
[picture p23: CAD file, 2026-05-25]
hardware/STEP/follower/eef/Gripper_gear.stp
23.6 x 24.0 x 10.0 mm

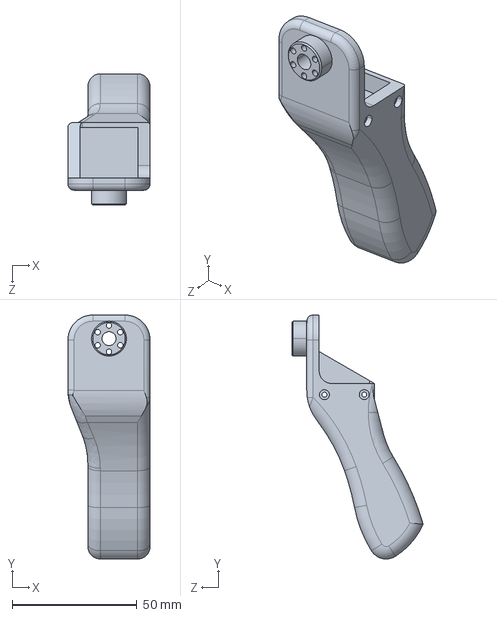
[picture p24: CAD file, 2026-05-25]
hardware/STEP/leader/handle/handel.stp
33.0 x 98.0 x 52.8 mm

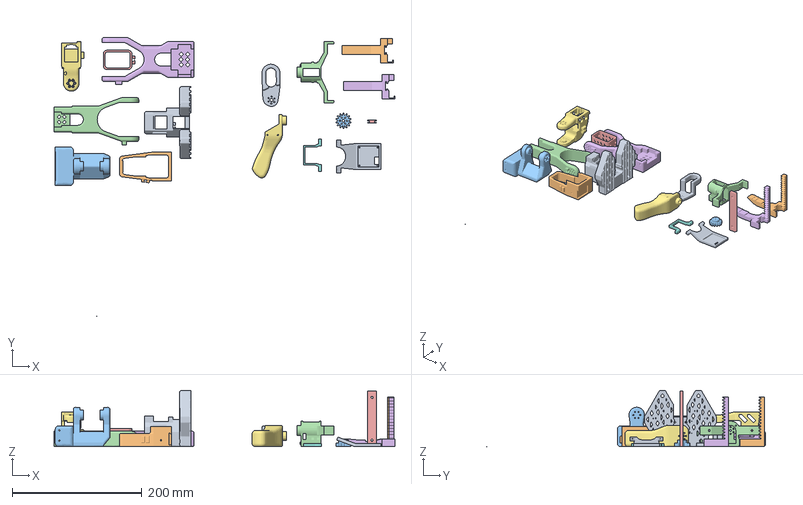
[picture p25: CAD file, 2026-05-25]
hardware/STL/UniArmL1.3mf
525.7 x 429.9 x 87.0 mm
Base.stl
Base_motor_holder.stl
Rotation_Pitch.stl
Under_arm.stl
Under_motor_holder.stl
Upper_arm.stl
Wrist_roll_pitch.stl
Camera_mount_down.stl
Camera_mount_up.stl
Finger.stl x 2
Gripper_gear.stl
Gripper_shell.stl
Guide_rail.stl
handel.STL
Trigger.stl x 2

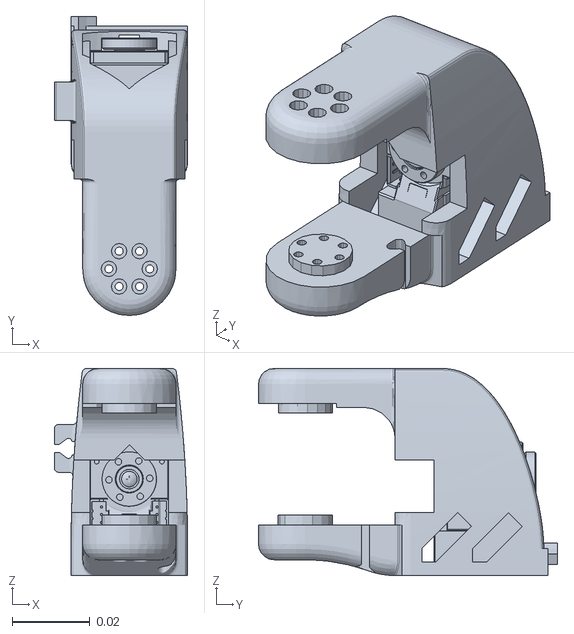
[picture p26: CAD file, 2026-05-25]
assets/uniarml1/meshes/Link_4.STL
0.0343 x 0.0769 x 0.0532

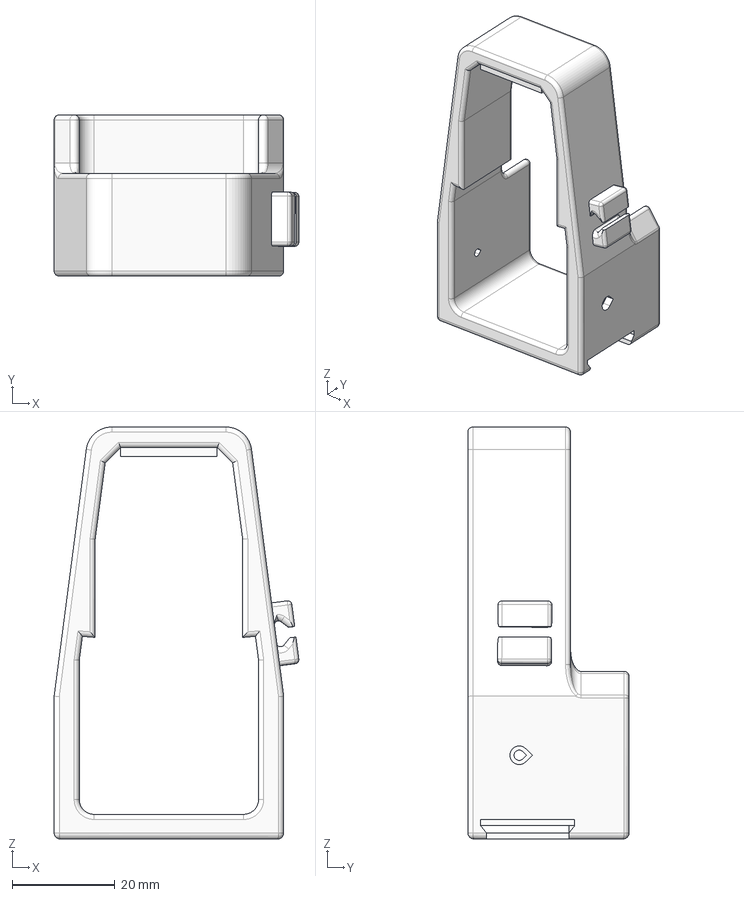
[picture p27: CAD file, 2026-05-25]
hardware/STEP/common/Base_motor_holder.stp
47.6 x 31.4 x 80.2 mm

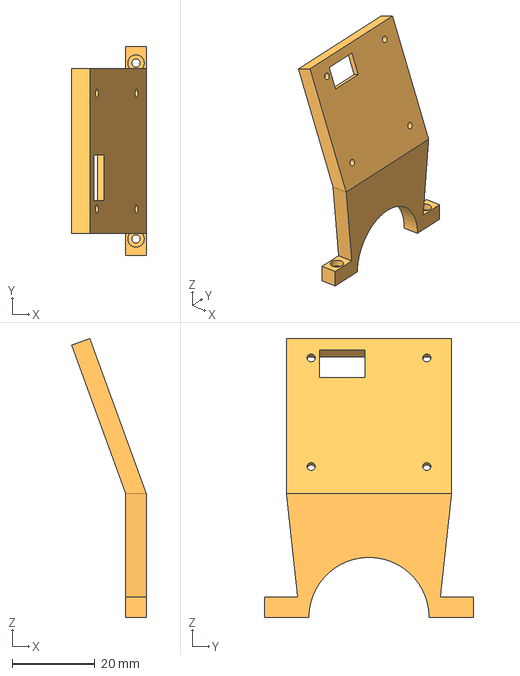
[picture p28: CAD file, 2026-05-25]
hardware/STEP/follower/camera/Camera_mount_up.stp
18.1 x 50.6 x 67.6 mm

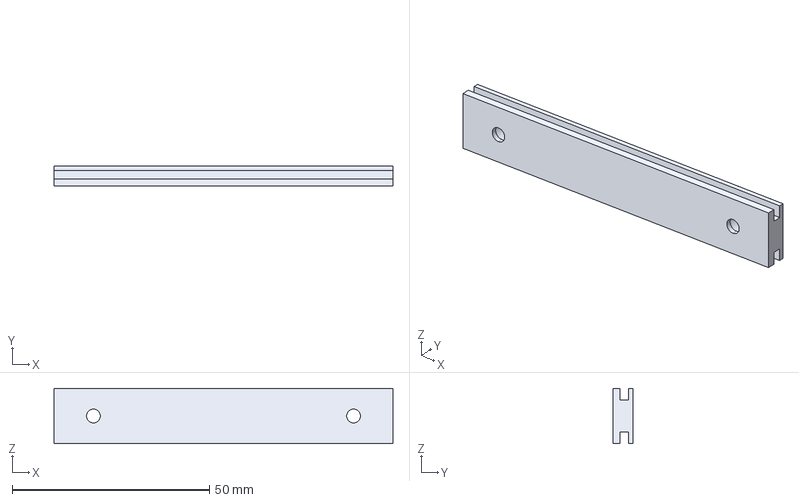
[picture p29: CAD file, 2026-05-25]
hardware/STEP/follower/eef/Guide_rail.stp
86.0 x 5.20 x 14.0 mm

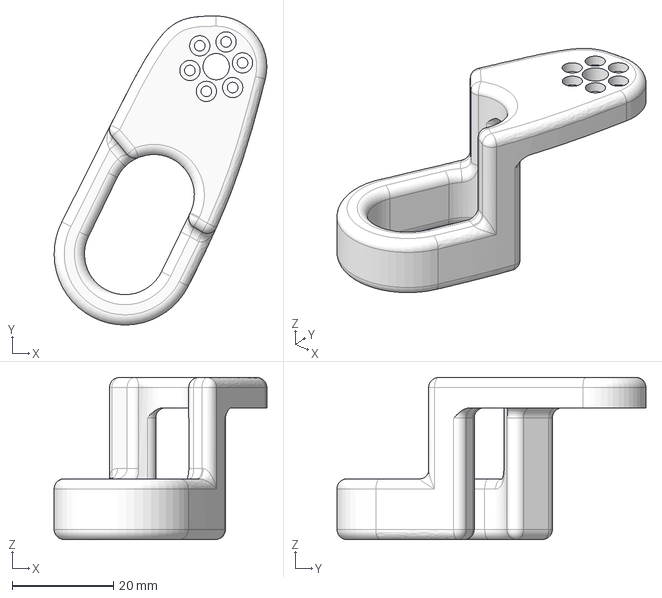
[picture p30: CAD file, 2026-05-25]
hardware/STEP/leader/handle/Trigger.stp
42.0 x 61.0 x 32.0 mm

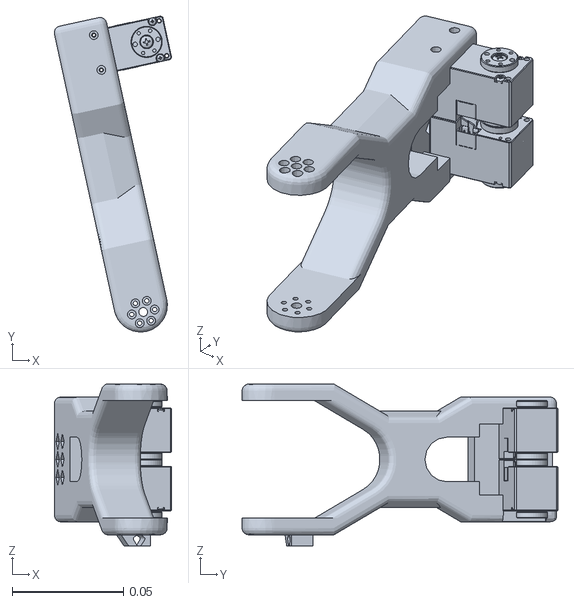
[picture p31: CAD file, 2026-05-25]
assets/uniarml1/meshes/Link_2.STL
0.0526 x 0.142 x 0.0727

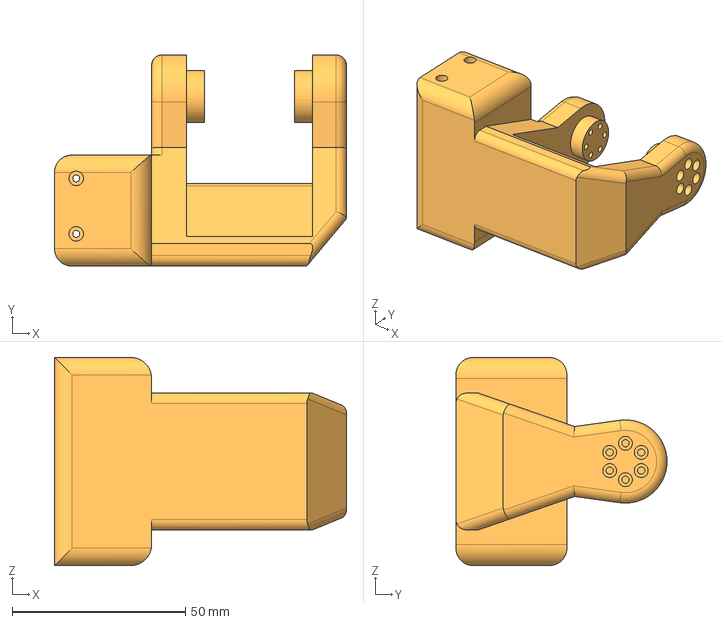
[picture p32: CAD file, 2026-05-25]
hardware/STEP/common/Rotation_Pitch.stp
84.2 x 60.9 x 60.0 mm

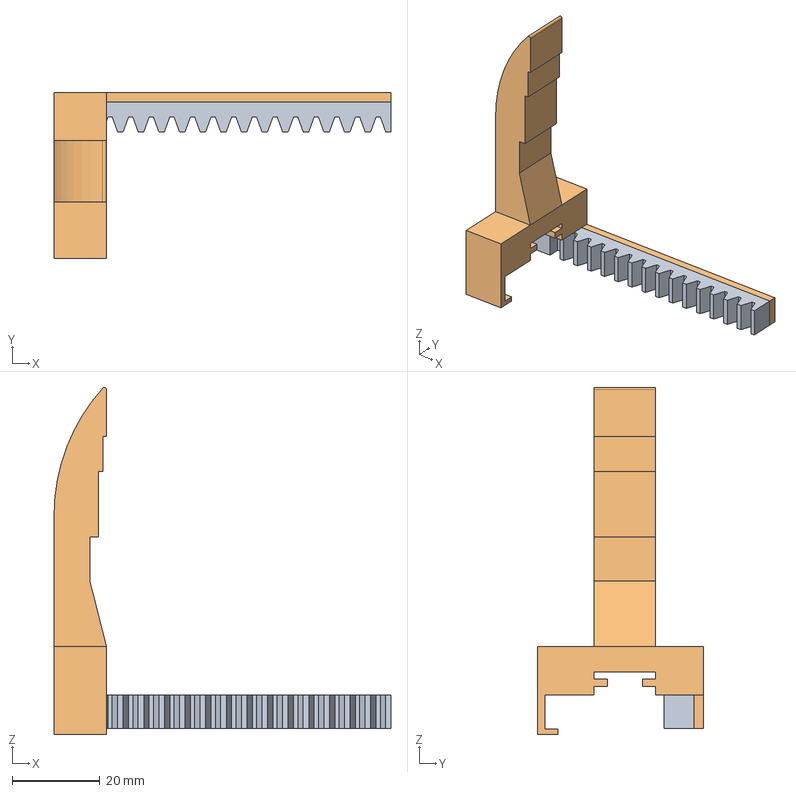
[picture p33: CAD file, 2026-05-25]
hardware/STEP/follower/eef/Finger.stp
77.0 x 38.0 x 79.3 mm

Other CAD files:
assets/uniarml1/meshes/gripper_l.STL
hardware/STEP/common/Under_motor_holder.stp
hardware/STEP/follower/eef/Gripper_shell.stp
assets/uniarml1/meshes/Link_1.STL
assets/uniarml1/meshes/Link_5.STL
assets/uniarml1/meshes/base_link.STL
assets/uniarml1/meshes/gripper_r.STL
assets/uniarml1/meshes/gripperframe.STL
hardware/STEP/common/Base.stp
hardware/STEP/common/Upper_arm.stp
hardware/STEP/common/Wrist_roll_pitch.stp
hardware/STEP/follower/eef/Gripper.STEP
hardware/STL/common/Base.stl
hardware/STL/common/Base_motor_holder.stl
hardware/STL/common/Rotation_Pitch.stl
hardware/STL/common/Under_arm.stl
hardware/STL/common/Under_motor_holder.stl
hardware/STL/common/Upper_arm.stl
hardware/STL/common/Wrist_roll_pitch.stl
hardware/STL/follower/camera/Camera_mount_down.stl
hardware/STL/follower/camera/Camera_mount_up.stl
hardware/STL/follower/eef/Finger.stl
hardware/STL/follower/eef/Gripper_gear.stl
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

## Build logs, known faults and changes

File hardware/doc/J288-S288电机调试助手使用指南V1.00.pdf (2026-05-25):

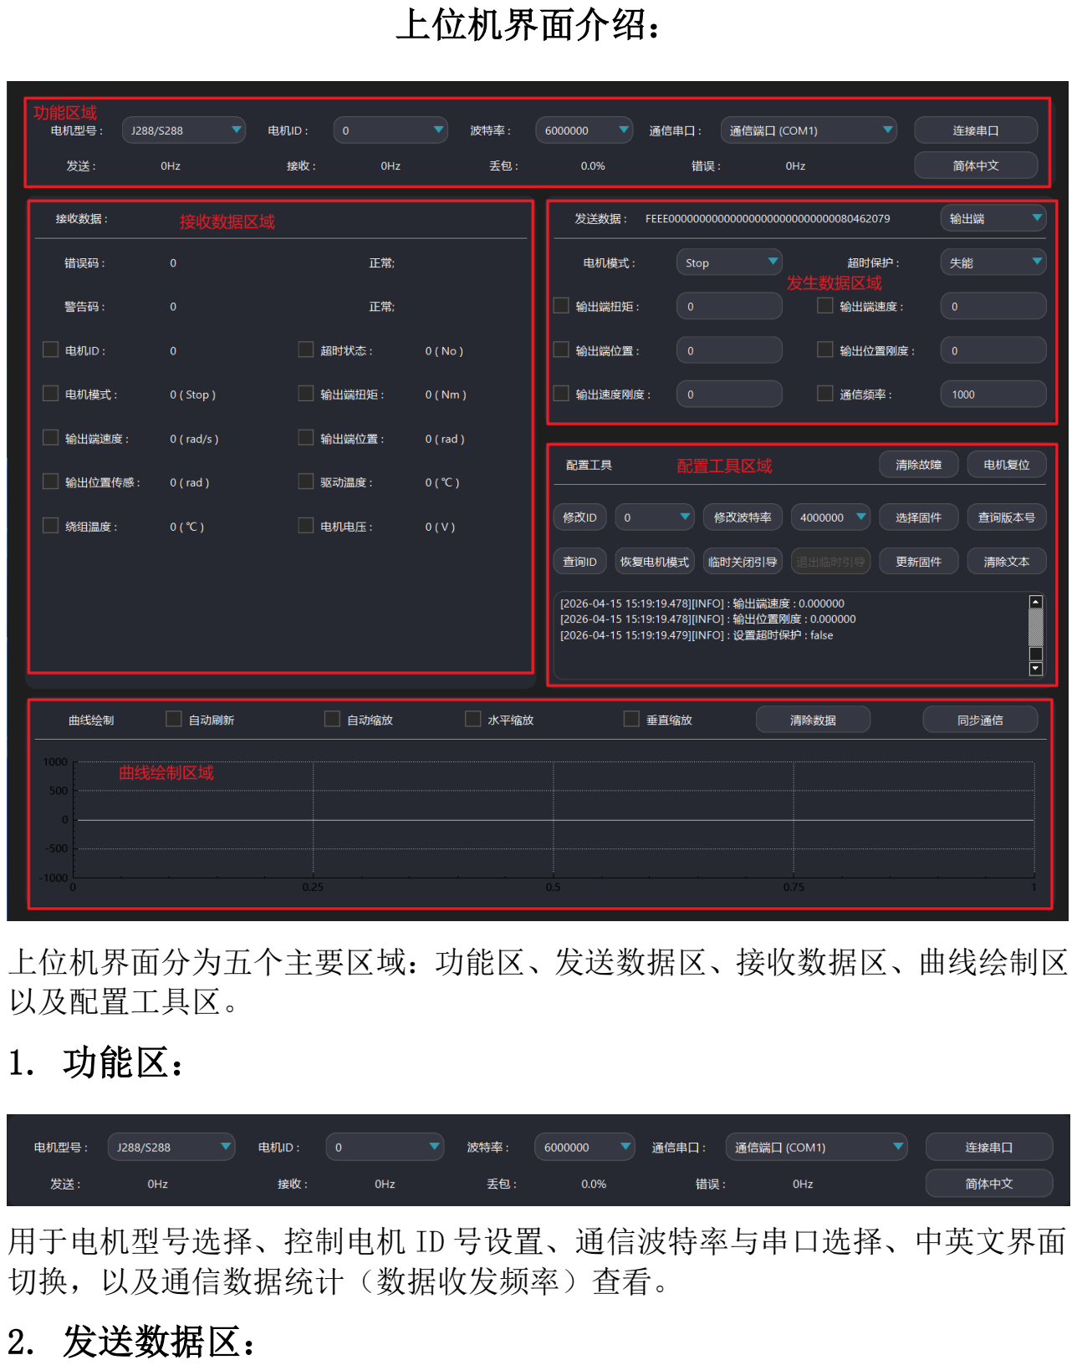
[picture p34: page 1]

上位机界面介绍：

上位机界面分为五个主要区域：功能区、发送数据区、接收数据区、曲线绘制区 以及配置工具区。
1. 功能区：

用于电机型号选择、控制电机 ID 号设置、通信波特率与串口选择、中英文界面 切换，以及通信数据统计（数据收发频率）查看。
2. 发送数据区：

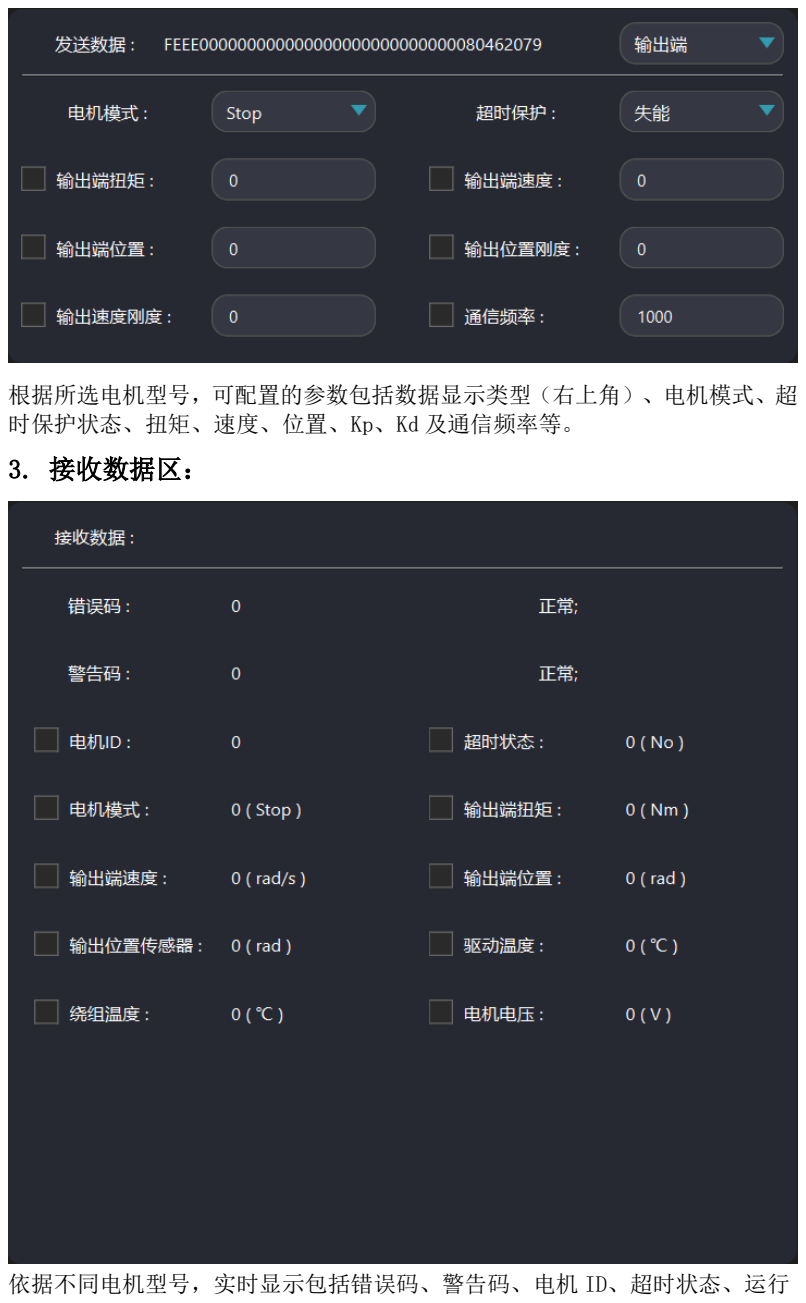
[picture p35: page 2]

根据所选电机型号，可配置的参数包括数据显示类型（右上角）、电机模式、超 时保护状态、扭矩、速度、位置、Kp、Kd 及通信频率等。
3. 接收数据区：

依据不同电机型号，实时显示包括错误码、警告码、电机 ID、超时状态、运行

模式、扭矩、速度、位置、温度和电压等数据。

4. 配置工具区：

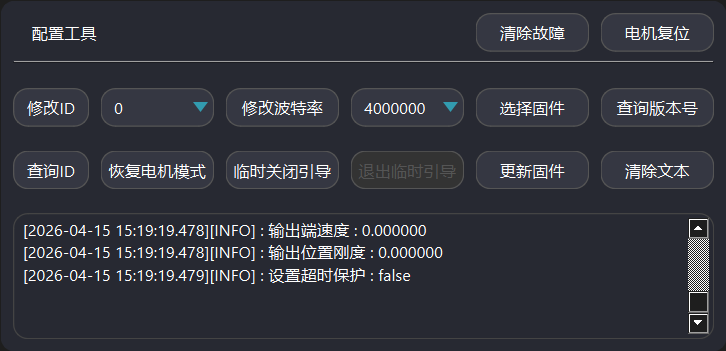
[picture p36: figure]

- 清除故障：清除电机故障码
- 电机复位：电机将执行软重启
- 修改 ID：将当前电机 ID 更改为指定的目标 ID。操作成功后，电机 ID 将更 新为目标值，同时上位机软件中控制的电机 ID 也将同步切换至新 ID
- 修改波特率：将电机通信波特率修改为指定波特率
- 选择固件：从本地文件中浏览并选择需要用于电机更新的固件文件，支持常 见格式的固件加载。
- 更新固件：将已选中的固件文件写入电机内部存储器中，完成电机程序的升 级或修复操作。此过程通常需保持电机与上位机稳定连接。
- 查询版本号：读取并显示当前连接电机的固件版本信息，用于判断电机状态 与兼容性。
- 查询 ID：扫描当前通信总线上所有在线的电机设备，并获取其 ID。若总线 上仅检测到一台电机，上位机会自动将控制 ID 切换为该电机 ID。若存在多 台电机，将鼠标悬停在查询按钮上可临时显示所有 ID，同时所有 ID 信息会 输出到文本框中，方便查看与记录。
- 恢复电机模式：使电机从其他状态（如 Bootloader）切换回正常的“APP 运 行阶段”，恢复电机常规控制功能。
- 临时关闭引导：将总线上所有电机临时切换到“Bootloader 阶段”，此时除 “退出临时引导”按钮外，上位机界面其他所有控件将暂时失效。重新上电 后，电机会恢复至默认的工作状态。
- 退出临时引导：用于解除“临时关闭引导”状态，恢复上位机全部控件的正 常功能，但总线上所有电机仍停留在“Bootloader 阶段”，需手动点击“恢 复电机模式”。
- 清除文本：一键清空当前界面中文本框内的全部文本内容。
5. 曲线绘制区域：

请在发送或接收数据区勾选您需要绘制的数据类型。手动调整坐标轴缩放时， 若缩放比例超出允许范围，系统将自动恢复至预设的默认比例。

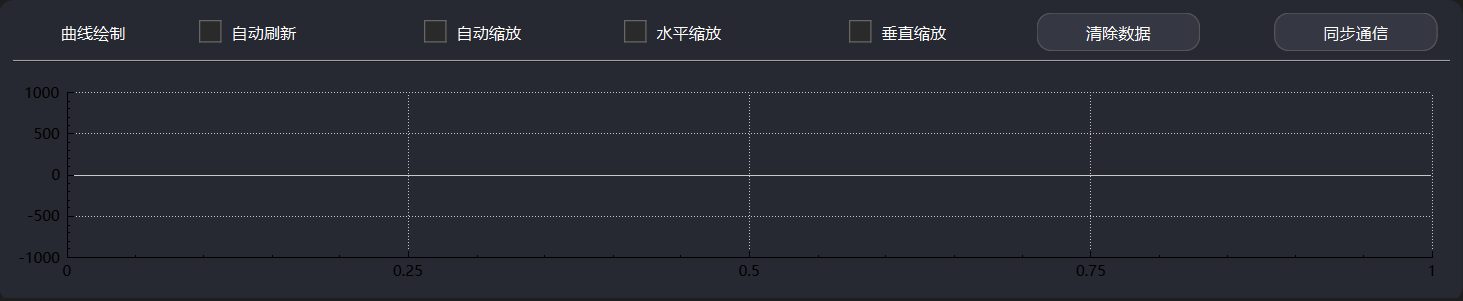
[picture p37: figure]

- 自动刷新：启用后，绘图区随最新数据自动滚动显示。
- 自动缩放：根据数据量自动调整 x 轴与 y 轴的显示范围。
- 水平缩放：在绘图区滑动鼠标滚轮可缩放 x 轴。
- 垂直缩放：在绘图区滑动鼠标滚轮可缩放 y 轴。
- 清除数据：清除所有已绘制的历史数据。
- 同步通信/异步通信：切换通信模式。同步通信按实际时间戳绘制数据，异 步通信则按接收顺序绘制。

首次使用需修改串口配置（通信频率>60Hz）

1、打开设备管理器：选中电脑桌面左下角图标右键唤出界面后选择设备管理器

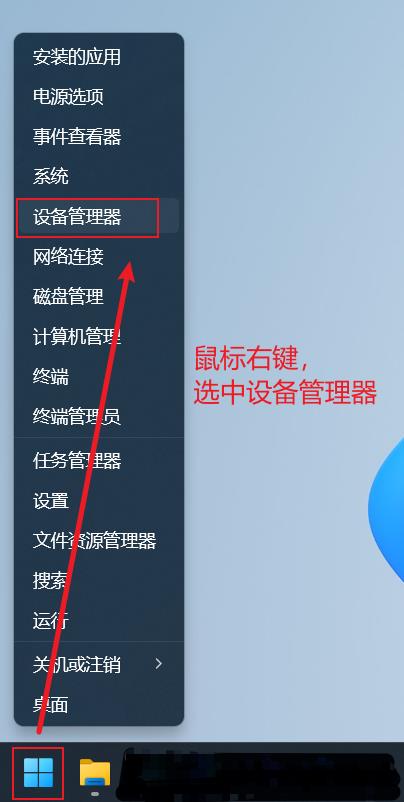
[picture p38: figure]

2、判断检测的串口

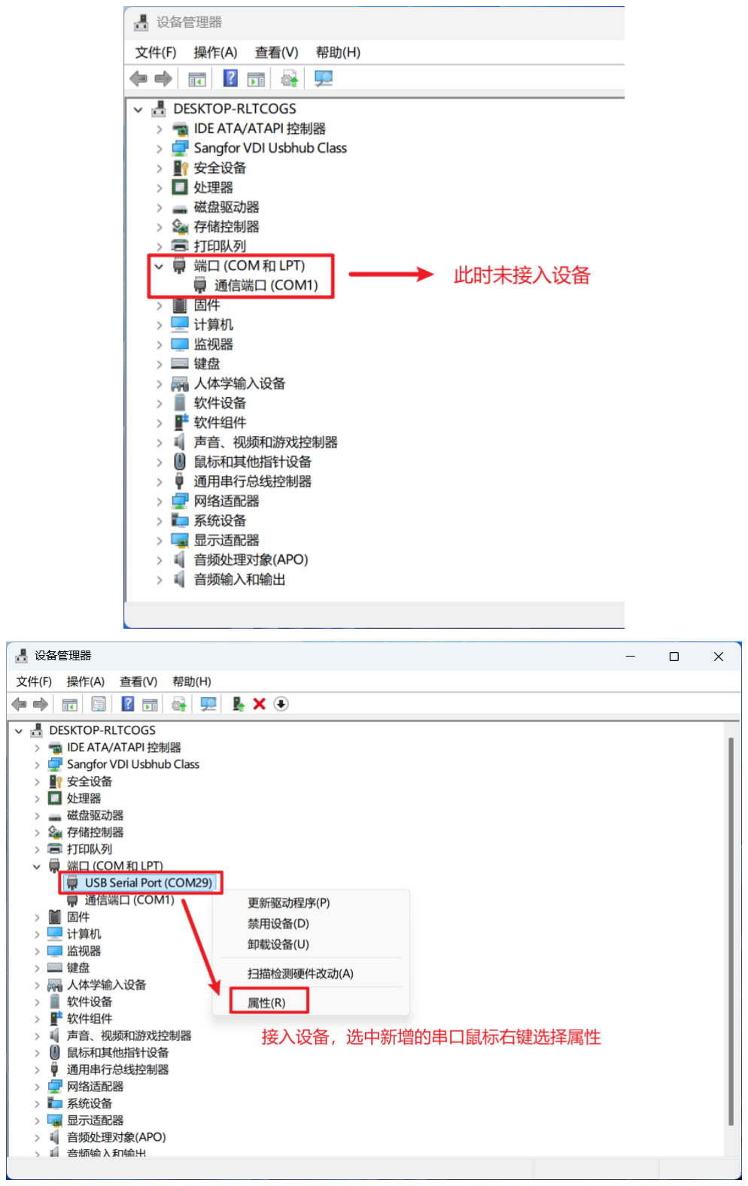
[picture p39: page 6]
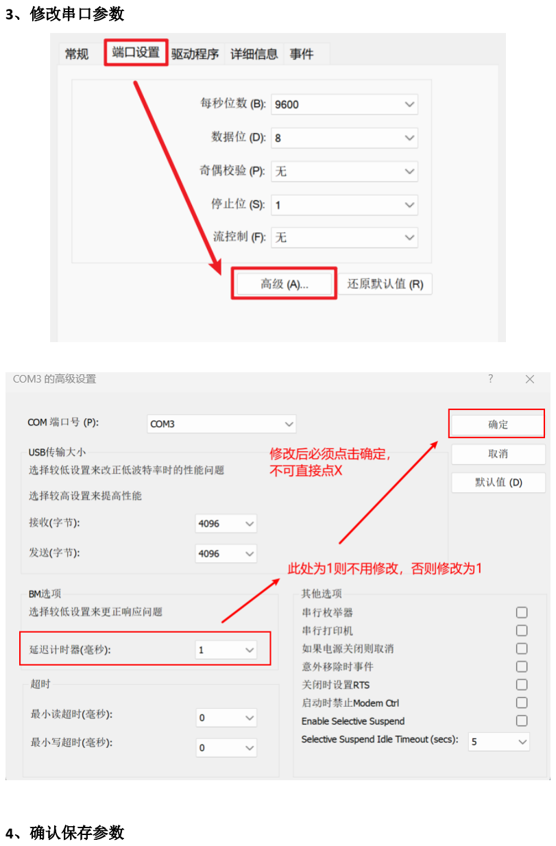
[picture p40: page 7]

3、修改串口参数

4、确认保存参数

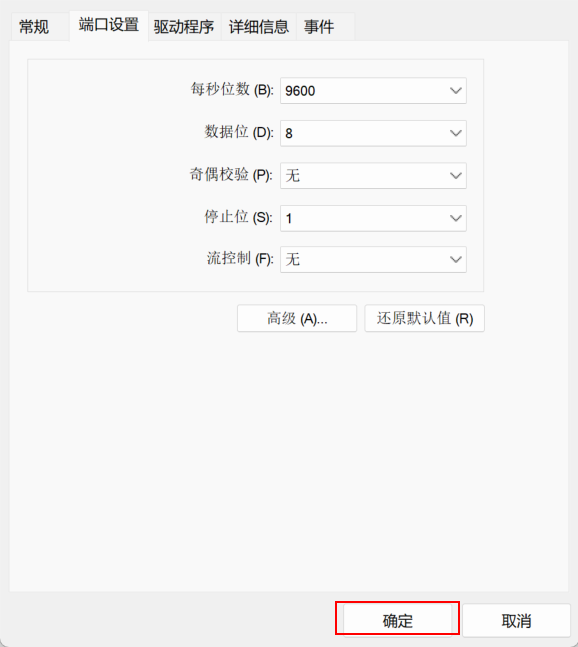
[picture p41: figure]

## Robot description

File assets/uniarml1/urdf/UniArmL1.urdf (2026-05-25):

<?xml version="1.0" encoding="utf-8"?>
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
<robot name="UniArmL1">
  <link name="base_link">
    <inertial>
      <origin xyz="-0.02868 -3.8976E-05 -0.031888" rpy="0 0 0" />
      <mass value="0.14867" />
      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
    </inertial>
    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
  </link>
  <link name="Link_1">
    <inertial>
      <origin xyz="0.031034 1.004E-08 0.011119" rpy="0 0 0" />
      <mass value="0.15781" />
      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
    </inertial>
    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
  </link>
  <joint name="shoulder_pan" type="revolute">
    <origin xyz="0 0 0.00014913" rpy="0 0 0" />
    <parent link="base_link" />
    <child link="Link_1" />
    <axis xyz="0 0 1" />
    <limit lower="-1.75" upper="1.75" effort="150" velocity="3.14" />
  </joint>
  <link name="Link_2">
    <inertial>
      <origin xyz="-0.0159 0.078763 -0.00010395" rpy="0 0 0" />
      <mass value="0.15798" />
      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
    </inertial>
    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
  </link>
  <joint name="shoulder_lift" type="revolute">
    <origin xyz="0.0316 0 0.059433" rpy="1.5708 0.21375 0" />
    <parent link="Link_1" />
    <child link="Link_2" />
    <axis xyz="0 0 1" />
    <limit lower="-1.87" upper="1.87" effort="150" velocity="3.14" />
  </joint>
  <link name="Link_3">
    <inertial>
      <origin xyz="0.00069195 -0.072761 0.00022473" rpy="0 0 0" />
      <mass value="0.09906" />
      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
    </inertial>
    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
  </link>
  <joint name="elbow_flex" type="revolute">
    <origin xyz="0.0015028 0.12124 0" rpy="3.1416 0 -1.3533" />
    <parent link="Link_2" />
    <child link="Link_3" />
    <axis xyz="0 0 -1" />
    <limit lower="-1.65" upper="1.65" effort="150" velocity="3.14" />
  </joint>
  <link name="Link_4">
    <inertial>
      <origin xyz="-0.00022101 0.029092 -0.00029356" rpy="0 0 0" />
      <mass value="0.08193" />
      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
    </inertial>
    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
  </link>
  <joint name="wrist_flex" type="revolute">
    <origin xyz="0 -0.132841538725229 0" rpy="3.14159265358979 0 0.00375109452477133" />
    <parent link="Link_3" />
    <child link="Link_4" />
    <axis xyz="0 0 1" />
    <limit lower="-1.62" upper="1.62" effort="150" velocity="150" />
  </joint>
  <link name="Link_5">
    <inertial>
      <origin xyz="0.0028274 -2.5466E-05 0.034839" rpy="0 0 0" />
      <mass value="0.07802" />
      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
    </inertial>
    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
  </link>
  <joint name="wrist_roll" type="revolute">
    <origin xyz="0 0.055776 -0.0022" rpy="-1.5708 0 0" />
    <parent link="Link_4" />
    <child link="Link_5" />
    <axis xyz="0 0 -1" />
    <limit lower="-2.885" upper="2.885" effort="150" velocity="3.14" />
  </joint>
  <link name="gripper_r">
    <inertial>
      <origin xyz="0.0095066 -0.26671 -0.027189" rpy="0 0 0" />
      <mass value="0.0102" />
      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
    </inertial>
    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
  </link>
  <joint name="gripper_r" type="prismatic">
    <origin xyz="0.17018 0 -0.13438" rpy="-1.5708 -0.74203 0" />
    <parent link="Link_5" />
    <child link="gripper_r" />
    <axis xyz="0 0 1" />
    <limit lower="0" upper="0.0285" effort="0" velocity="0" />
  </joint>
  <link name="gripper_l">
    <inertial>
      <origin xyz="0.014 -0.26259 0.02719" rpy="0 0 0" />
      <mass value="0.0102" />
      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
    </inertial>
    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
  </link>
  <joint name="gripper_l" type="prismatic">
    <origin xyz="0.17018 0 -0.13438" rpy="-1.5708 -0.74203 0" />
    <parent link="Link_5" />
    <child link="gripper_l" />
    <axis xyz="0 0 -1" />
    <limit lower="0" upper="0.0285" effort="0" velocity="0" />
  </joint>
  <link name="gripperframe">
    <inertial>
      <origin xyz="0.069061 0.0018966 -0.040643" rpy="0 0 0" />
      <mass value="1E-05" />
      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
    </inertial>
    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
  </link>
  <joint name="gripperframe_joint" type="fixed">
    <origin xyz="0.17018 0 -0.13438" rpy="0 0 3.1416" />
    <parent link="Link_5" />
    <child link="gripperframe" />
    <axis xyz="0 0 0" />
    <limit lower="0" upper="0" effort="0" velocity="0" />
  </joint>
</robot>

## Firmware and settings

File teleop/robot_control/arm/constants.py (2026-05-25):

import math

# 通信协议基础定义
BAUDRATE = 6000000        # 通信波特率固定为 6Mbps [cite: 43, 67]
HEAD_TX = b'\xfe\xee'     # 发送指令帧头 (2字节) 
HEAD_RX = b'\xfc\xee'     # 接收反馈帧头 (2字节) 
TX_LEN = 20               # 控制命令数据包长度 (20字节) [cite: 75]
RX_LEN = 26               # 反馈数据包长度 (26字节) [cite: 95]

GEAR_RATIO = 288.35

# 物理量换算系数 
K_POS = 32768 / (2 * math.pi)        # 1 rad = 32768/2
K_SPEED = 32768 / (2 * math.pi)         # 1 rad/s = 2.56/2
K_TORQUE = 256000.0    # 1 Nm = 256000
K_KP = 1280000.0       # 1 unit = 1280000
K_KD = 128000000.0     # 1 unit = 128000000
K_VOLTAGE = 0.5


OUT_POS_RES = 8192 # 输出端 13 位绝对位置传感器 (2^13 = 8192 表示 1 圈) [cite: 108]

# 故障码定义 [cite: 141]
ERROR_MAP = {
    0x01:     "过流",
    0x02:     "瞬态过压",
    0x04:     "持续过压",
    0x08:     "欠压",
    0x10:     "芯片过热",
    0x20:     "MOS 过热",
    0x40:     "MOS 温度异常",
    0x80:     "壳体过热",
    0x100:    "壳体温度异常",
    0x200:    "绕组过热",
    0x400:    "转子编码器1错误",
    0x800:    "转子编码器2错误",
    0x1000:   "输出编码器错误",
    0x40000:  "通信校验错误",
}


CRC32_TABLE = [
    0x00000000, 0x04C11DB7, 0x09823B6E, 0x0D4326D9, 0x130476DC, 0x17C56B6B, 0x1A864DB2, 0x1E475005,
    0x2608EDB8, 0x22C9F00F, 0x2F8AD6D6, 0x2B4BCB61, 0x350C9B64, 0x31CD86D3, 0x3C8EA00A, 0x384FBDBD,
    0x4C11DB70, 0x48D0C6C7, 0x4593E01E, 0x4152FDA9, 0x5F15ADAC, 0x5BD4B01B, 0x569796C2, 0x52568B75,
    0x6A1936C8, 0x6ED82B7F, 0x639B0DA6, 0x675A1011, 0x791D4014, 0x7DDC5DA3, 0x709F7B7A, 0x745E66CD,
    0x9823B6E0, 0x9CE2AB57, 0x91A18D8E, 0x95609039, 0x8B27C03C, 0x8FE6DD8B, 0x82A5FB52, 0x8664E6E5,
    0xBE2B5B58, 0xBAEA46EF, 0xB7A96036, 0xB3687D81, 0xAD2F2D84, 0xA9EE3033, 0xA4AD16EA, 0xA06C0B5D,
    0xD4326D90, 0xD0F37027, 0xDDB056FE, 0xD9714B49, 0xC7361B4C, 0xC3F706FB, 0xCEB42022, 0xCA753D95,
    0xF23A8028, 0xF6FB9D9F, 0xFBB8BB46, 0xFF79A6F1, 0xE13EF6F4, 0xE5FFEB43, 0xE8BCCD9A, 0xEC7DD02D,
    0x34867077, 0x30476DC0, 0x3D044B19, 0x39C556AE, 0x278206AB, 0x23431B1C, 0x2E003DC5, 0x2AC12072,
    0x128E9DCF, 0x164F8078, 0x1B0CA6A1, 0x1FCDBB16, 0x018AEB13, 0x054BF6A4, 0x0808D07D, 0x0CC9CDCA,
    0x7897AB07, 0x7C56B6B0, 0x71159069, 0x75D48DDE, 0x6B93DDDB, 0x6F52C06C, 0x6211E6B5, 0x66D0FB02,
    0x5E9F46BF, 0x5A5E5B08, 0x571D7DD1, 0x53DC6066, 0x4D9B3063, 0x495A2DD4, 0x44190B0D, 0x40D816BA,
    0xACA5C697, 0xA864DB20, 0xA527FDF9, 0xA1E6E04E, 0xBFA1B04B, 0xBB60ADFC, 0xB6238B25, 0xB2E29692,
    0x8AAD2B2F, 0x8E6C3698, 0x832F1041, 0x87EE0DF6, 0x99A95DF3, 0x9D684044, 0x902B669D, 0x94EA7B2A,
    0xE0B41DE7, 0xE4750050, 0xE9362689, 0xEDF73B3E, 0xF3B06B3B, 0xF771768C, 0xFA325055, 0xFEF34DE2,
    0xC6BCF05F, 0xC27DEDE8, 0xCF3ECB31, 0xCBFFD686, 0xD5B88683, 0xD1799B34, 0xDC3ABDED, 0xD8FBA05A,
    0x690CE0EE, 0x6DCDFD59, 0x608EDB80, 0x644FC637, 0x7A089632, 0x7EC98B85, 0x738AAD5C, 0x774BB0EB,
    0x4F040D56, 0x4BC510E1, 0x46863638, 0x42472B8F, 0x5C007B8A, 0x58C1663D, 0x558240E4, 0x51435D53,
    0x251D3B9E, 0x21DC2629, 0x2C9F00F0, 0x285E1D47, 0x36194D42, 0x32D850F5, 0x3F9B762C, 0x3B5A6B9B,
    0x0315D626, 0x07D4CB91, 0x0A97ED48, 0x0E56F0FF, 0x1011A0FA, 0x14D0BD4D, 0x19939B94, 0x1D528623,
    0xF12F560E, 0xF5EE4BB9, 0xF8AD6D60, 0xFC6C70D7, 0xE22B20D2, 0xE6EA3D65, 0xEBA91BBC, 0xEF68060B,
    0xD727BBB6, 0xD3E6A601, 0xDEA580D8, 0xDA649D6F, 0xC423CD6A, 0xC0E2D0DD, 0xCDA1F604, 0xC960EBB3,
    0xBD3E8D7E, 0xB9FF90C9, 0xB4BCB610, 0xB07DABA7, 0xAE3AFBA2, 0xAAFBE615, 0xA7B8C0CC, 0xA379DD7B,
    0x9B3660C6, 0x9FF77D71, 0x92B45BA8, 0x9675461F, 0x8832161A, 0x8CF30BAD, 0x81B02D74, 0x857130C3,
    0x5D8A9099, 0x594B8D2E, 0x5408ABF7, 0x50C9B640, 0x4E8EE645, 0x4A4FFBF2, 0x470CDD2B, 0x43CDC09C,
    0x7B827D21, 0x7F436096, 0x7200464F, 0x76C15BF8, 0x68860BFD, 0x6C47164A, 0x61043093, 0x65C52D24,
    0x119B4BE9, 0x155A565E, 0x18197087, 0x1CD86D30, 0x029F3D35, 0x065E2082, 0x0B1D065B, 0x0FDC1BEC,
    0x3793A651, 0x3352BBE6, 0x3E119D3F, 0x3AD08088, 0x2497D08D, 0x2056CD3A, 0x2D15EBE3, 0x29D4F654,
    0xC5A92679, 0xC1683BCE, 0xCC2B1D17, 0xC8EA00A0, 0xD6AD50A5, 0xD26C4D12, 0xDF2F6BCB, 0xDBEE767C,
    0xE3A1CBC1, 0xE760D676, 0xEA23F0AF, 0xEEE2ED18, 0xF0A5BD1D, 0xF464A0AA, 0xF9278673, 0xFDE69BC4,
    0x89B8FD09, 0x8D79E0BE, 0x803AC667, 0x84FBDBD0, 0x9ABC8BD5, 0x9E7D9662, 0x933EB0BB, 0x97FFAD0C,
    0xAFB010B1, 0xAB710D06, 0xA6322BDF, 0xA2F33668, 0xBCB4666D, 0xB8757BDA, 0xB5365D03, 0xB1F740B4
]

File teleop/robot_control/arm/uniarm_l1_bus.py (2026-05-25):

# unitree.py 核心部分备份

import struct
import time
import serial
import math
import numpy as np
import logging
import threading
from dataclasses import dataclass
import sys
import time
from .constants import (
    BAUDRATE, HEAD_TX, HEAD_RX, RX_LEN, GEAR_RATIO,
    K_POS, K_SPEED, K_TORQUE, K_KP, K_KD, K_VOLTAGE,
    OUT_POS_RES, ERROR_MAP,CRC32_TABLE
)
from .utiles import (
    OutPosRaw2OutPos_rad, rad2deg, deg2rad, OutPos_rad2OutPosRaw,
)

logger = logging.getLogger(__name__)

@dataclass
class MotorState:
    id: int
    mode: int = 0
    timeout: int = 0
    temp_case: int = 0
    temp_winding: int = 0
    voltage: float = 0.0
    torque_nm: float = 0.0
    speed_rads: float = 0.0
    pos_rad: float = 0.0
    pos_raw_rad: int = 0
    MError: int = 0
    ExFlag: int = 0
    OutPos: int = 0
    OutPos_rad: float = 0.0
    OutPos_deg: float = 0.0
    CRC32: int = 0
    freq: float = 0.0
    last_update: float = time.perf_counter()
    pos_rad_threshold: float = 20.0


class UnitreeMotorSDK:
    """Unitree 电机 SDK - 单总线半双工通信，支持位置、速度、力矩控制模式，带 CRC 校验和连续位置跟踪"""

    def __init__(self, motor_ids, port: str):
        self.ser = serial.Serial(
            port,
            BAUDRATE,
            timeout=0.01,
            bytesize=serial.EIGHTBITS,
            parity=serial.PARITY_NONE,
            stopbits=serial.STOPBITS_ONE,
            xonxoff=False,
            rtscts=False,
            dsrdtr=False,
        )
        self.motor_states = {motor_id: MotorState(id=motor_id) for motor_id in motor_ids}
        self.verbose_errors = False
        self._serial_lock = threading.RLock()
        self.last_valid_time = {}
        self.pos_rad_unwrapped = {motor_id: 0.0 for motor_id in motor_ids}  # 追踪 unwrapped 位置
        self.output_zero_offset = {motor_id: None for motor_id in motor_ids}
    @staticmethod
    def _wrap_0_2pi(x):
        two_pi = 2.0 * math.pi
        return x % two_pi

    def _ensure_output_offset(self, motor_id: int):
        st = self.motor_states[motor_id]
        if self.output_zero_offset[motor_id] is None:
            raw_cont = st.pos_rad
            raw_mod = self._wrap_0_2pi(raw_cont)
            self.output_zero_offset[motor_id] = self._wrap_0_2pi(st.OutPos_rad - raw_mod)
    def get_output_pos_cont_aligned(self, motor_id: int) -> float:
        self._ensure_output_offset(motor_id)
        st = self.motor_states[motor_id]
        offset = self.output_zero_offset[motor_id]
        if offset is None:
            offset = 0.0
        return st.pos_rad + offset
    @staticmethod
    def crc32_lookup(data: bytes) -> int:
        crc = 0xFFFFFFFF
        n = len(data)
        i = 0
        while i + 3 < n:
            b0 = data[i + 3]
            b1 = data[i + 2]
            b2 = data[i + 1]
            b3 = data[i]
            crc = CRC32_TABLE[(crc >> 24) ^ b0] ^ ((crc << 8) & 0xFFFFFFFF)
            crc = CRC32_TABLE[(crc >> 24) ^ b1] ^ ((crc << 8) & 0xFFFFFFFF)
            crc = CRC32_TABLE[(crc >> 24) ^ b2] ^ ((crc << 8) & 0xFFFFFFFF)
            crc = CRC32_TABLE[(crc >> 24) ^ b3] ^ ((crc << 8) & 0xFFFFFFFF)
            i += 4
        return crc

    def write_control_packet(self, motor_id: int, pos: float = 0.0, kp: float = 1.8e-4,
            kd: float = 4.1e-5, torque: float = 0.0, speed: float = 0.5e-8,
            status: int = 1, timeout_enable: int = 0):
        """
        这里把传入的 pos 统一解释为：输出端单圈目标角(rad)
        内部自动转换成：最近连续目标角
        """

        mode_byte = (motor_id & 0x0F) | ((status & 0x07) << 4) | ((timeout_enable & 0x01) << 7)
        st = self.motor_states[motor_id]

        two_pi = 2.0 * math.pi

        # 当前连续输出端位置（由返回的 pos 换算）
        cur_pos_cont = st.pos_rad

        # 当前输出端单圈角 [0, 2π)
        cur_pos_mod = st.OutPos_rad

        # 目标也强制解释成单圈角
        pos_mod = pos % two_pi

        # 单圈最短路径误差
        delta = pos_mod - cur_pos_mod
        delta = (delta + math.pi) % two_pi - math.pi

        # 最近连续目标
        pos_cont = cur_pos_cont + delta

        raw_tor = max(-32768, min(32767, int((torque / GEAR_RATIO) * K_TORQUE)))
        raw_spd = max(-32768, min(32767, int((speed * GEAR_RATIO) * K_SPEED)))
        raw_pos = int((pos_cont * GEAR_RATIO) * K_POS)
        raw_kp = max(0, min(32767, int(kp * K_KP)))
        raw_kd = max(0, min(32767, int(kd * K_KD)))

        self._ensure_output_offset(motor_id)
        aligned_cont = self.get_output_pos_cont_aligned(motor_id)

        # if motor_id == 3:
        #     print(
        #         f"[mid={motor_id}] "
        #         f"cmd_in={pos:.4f}, pos_mod={pos_mod:.4f}, "
        #         f"cur_mod={cur_pos_mod:.4f}, raw_cont={cur_pos_cont:.4f}, "
        #         f"aligned_cont={aligned_cont:.4f}, "
        #         f"delta={delta:.4f}, pos_cont={pos_cont:.4f}, raw_pos={raw_pos}"
        #     )
        payload = struct.pack("<BBhhihh", mode_byte, 0, raw_tor, raw_spd, raw_pos, raw_kp, raw_kd)
        packet_without_crc = HEAD_TX + payload
        crc = self.crc32_lookup(packet_without_crc)
        full_packet = packet_without_crc + struct.pack('<I', crc)
        assert len(full_packet) == 20
        self.ser.write(full_packet)
        

    def read(self):
        """接收反馈包（仿照工作版本的超时等待逻辑，但跳过 CRC）"""
        data = self.ser.read(26)
        if len(data) != 26:
            return None
        if data[0] != 0xFC or data[1] != 0xEE:
            return None

        mode_byte = data[2]
        motor_id = mode_byte & 0x0F
        mode = (mode_byte >> 4) & 0x07
        timeout = (mode_byte >> 7) & 0x01
        # 提取 19 字节的 fbk 数据
        fbk = data[3:22]  # 22 - 3 = 19
        if len(fbk) != 19:
            return None

        try:
            temp, sensor, vol, torque, speed, pos, MError, outpos_exflag, exsensor2, excom = \
                struct.unpack('<bbb hh i I H BB', fbk)
        except struct.error as e:
            print(f"[解析错误] {e}, fbk length={len(fbk)}")
            return None

        # 分离位域
        OutPos = outpos_exflag & 0x1FFF      # 低13位
        ExFlag = (outpos_exflag >> 13) & 0x07  # 高3位

        # CRC 校验：从 mode_byte 开始共 20 字节（data[2:22]）
        crc_received = struct.unpack('<I', data[22:26])[0]
        crc_computed = self.crc32_lookup(data[2:22])
        if crc_received != crc_computed:
            return None

        # 转换为物理量
        vol_f = vol / 2.0
        ExPos = 2 * math.pi * OutPos / 8192.0
        outputSpd = (speed / 2.56) * 2 * math.pi / GEAR_RATIO
        outputTor = (torque / 256000.0) * GEAR_RATIO
        outputPos = 2 * math.pi * pos / 32768.0 / GEAR_RATIO
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

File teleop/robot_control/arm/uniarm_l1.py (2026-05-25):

import logging
import time
import threading
from pathlib import Path
from dataclasses import dataclass

import pinocchio as pin
import numpy as np
from scipy.spatial.transform import Rotation as R

from image_server.utils import make_cameras_from_configs

from .config_uniarm_l1 import UniArmL1RobotConfig
from .uniarm_l1_bus import UnitreeMotorsBus
from .constants import OUT_POS_RES
from .utiles import OutPosRaw2OutPos_rad
from .kinematics import RobotKinematics

logger = logging.getLogger(__name__)
@dataclass
class MotorCalibration:
    motor_id: int
    joint_name: str
    homing_offset: float
    range_min: float
    range_max: float

class UniArmL1:
    """UniArmL1 robot controller."""

    name = "uniarm_l1_follower"

    def __init__(self, config: UniArmL1RobotConfig):
        self.config = config

        # Motor configuration: supports dual-motor joints
        self.joint_motor_ids = config.joint_motor_ids
        self.motor_names = list(self.joint_motor_ids.keys())
        self.n_joints = len(self.motor_names)

        # Get all motor IDs list
        motor_ids = []
        self.motor_to_joint = {}  # motor_id -> joint_name reverse mapping
        for joint_name, ids in self.joint_motor_ids.items():
            for mid in ids:
                motor_ids.append(mid)
                self.motor_to_joint[mid] = joint_name
        self.motor_ids = sorted(motor_ids)
        self.n_motors = len(self.motor_ids)
    
        

        self.cameras = make_cameras_from_configs(config.cameras)
        self.urdf_path = config.urdf_path
        self.mesh_dir = Path(self.urdf_path).parent if self.urdf_path else None
        self.pin_model = pin.buildModelFromUrdf(self.urdf_path)
        self.pin_data = self.pin_model.createData()

        # IK configuration
        if self.urdf_path is None:
            raise ValueError("URDF path must not be None for IK solver initialization.")

        self.ik_solver = RobotKinematics(
            urdf_path=self.urdf_path,
            target_frame_name="Link_5",
            joint_names=self.motor_names[:5],
        )

        self.ik_solver.set_joint_preferences({
            "shoulder_pan": 0.5,
            "shoulder_lift": 0.3,
            "elbow_flex": 0.3,
            "wrist_flex": 0.3,
            "wrist_roll": 0.5,
        })

        self.calibration = {}
        self._running = False
        self._control_thread = None

        # Joint-level data (n_joints = 6)
        self.homing_rad = np.zeros(self.n_joints)
        self.range_min_rad = np.zeros(self.n_joints)
        self.range_max_rad = np.zeros(self.n_joints)
        self.q_current_sim = np.zeros(self.n_joints)
        self.tgt_pos_rad = np.zeros(self.n_motors)
        self.ratio_sim_phys = np.zeros(self.n_joints)
        self.phys_spans = np.zeros(self.n_joints)
        self.sim_spans = np.zeros(self.n_joints)
        self.home_set = np.zeros(self.n_joints)

        # Motor-level data (n_motors = 8)
        self.cur_pos_rad = np.zeros(self.n_motors)
        self.tgt_tau = np.zeros(self.n_motors)
        self.v_current_sim = np.zeros(self.n_joints)
        self.a_current_sim = np.zeros(self.n_joints)
        self.v_last_sim = np.zeros(self.n_joints)
        self.last_dyn_time = time.time()

        self.con_mode = np.zeros(self.n_motors)
        self.calibration_fpath = Path.home() / f".cache/unitree/calibration/{config.id}.json"

        # Default values
        self.kp_torque = [0.3, 1.6, 0.55, 0.6, 0.2, 0.1, 1.2, 0.45]
        self.kd_torque = [0.001, 0.004, 0.02, 0.038, 0.012, 0.001, 0.0005, 0.016]
        self.max_torque = [1.5, 3.0, 2.0, 1.5, 1.5, 1.5, 3.0, 2.0]

        # Individual homing and range for each motor (8 motors)
        self.motor_homing_rad = np.zeros(self.n_motors)
        self.motor_range_min_rad = np.zeros(self.n_motors)
        self.motor_range_max_rad = np.zeros(self.n_motors)

        # Try loading calibration from file
        self._load_calibration_from_file()

        # Initialize only when calibration has data
        if self.calibration:
            self.init_rate_phys_sim_spans()
            self.init_homing_rad()

        # home_set: home position in sim space
        # joint 0: middle, 1: large, 2: small, 3: small, 4: middle, 5: middle
        self.home_set = np.zeros(self.n_joints)
        for i, joint_name in enumerate(self.motor_names):
            q_min, q_max = self._get_joint_limits(joint_name)
            if q_min is None or q_max is None:
                continue
            if i in [1]:  # large
                self.home_set[i] = q_max
            elif i in [2, 3]:  # small
                self.home_set[i] = q_min
            else:  # middle (0, 4, 5)
                self.home_set[i] = (q_min + q_max) / 2
        self.sim_last = np.zeros(self.n_joints)
        self.t_start = time.time()
        self.init_finish = False
        self.last = 6.0

        # Try connecting hardware, fallback to simulation mode if failed
        if self.config.no_real_robot:
            print("⚠️ no_real_robot=True, using simulation mode")
            self.bus = None
            self.sim_mode = True
        else:
            try:
                self.bus = UnitreeMotorsBus(port=self.config.port, motor_ids=self.motor_ids)
                self.bus.range_max_rad = self.motor_range_max_rad.copy()
                self.bus.range_min_rad = self.motor_range_min_rad.copy()
                self.sim_mode = False
            except Exception as e:
                print(f"⚠️ Failed to connect to hardware ({e}), using simulation mode")
                self.bus = None
                self.sim_mode = True
        self.ee_state = 0

        self.teleop_enabled = True
        self._step_first_active = True
        # Initial pose (sim space)
        self.q_init_sim_rad = np.array([0.0, 0.7, -0.5, -0.9, 0.0, 0.0])
        self.q_init_rad = self.map_sim_to_output_rad_all(self.q_init_sim_rad)
        self.last_sim_q_deg = np.rad2deg(self.q_init_sim_rad)
        self.ee_pose = self.ik_solver.forward_kinematics(self.last_sim_q_deg[:5])
        self.target_pos_base = self.ee_pose[:3, 3]
        self.target_ori = self.ee_pose[:3, :3]


    def init_homing_rad(self):
        """Initialize individual homing and range for each motor."""
        # First initialize individual data for each motor
        for motor_id in self.motor_ids:
            cal = self.calibration.get(motor_id)
            if cal is None:
                print(f"Warning: No calibration for motor {motor_id}")
                continue
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
